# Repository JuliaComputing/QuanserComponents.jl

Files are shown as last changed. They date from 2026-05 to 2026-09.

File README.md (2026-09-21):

# QuanserComponents

Dyad models of the Quanser QUBE-Servo 3 with the rotary pendulum attachment (a Furuta
pendulum): a multibody plant, a clocked swing-up and balancing controller, and the
components that let the same controller run on the real device as a synchronous program.

https://github.com/user-attachments/assets/5ebe76e0-c05f-45de-a816-7d8e877a1d93

## Installation

The package and its Dyad dependencies are registered in the
[DyadRegistry](https://github.com/JuliaComputing/DyadRegistry); everything else comes from
the General registry. The generated Julia code is checked in, so the Dyad compiler is not
needed to use the package.

```julia
pkg> registry add https://github.com/JuliaComputing/DyadRegistry
pkg> add https://github.com/JuliaComputing/QuanserComponents.jl
```

or, for development, clone the repository and `pkg> dev path/to/QuanserComponents`.

The snippets below reach for four of the dependencies by name, so add them to the
environment as well:

```julia
pkg> add ModelingToolkit MultibodyComponents SynchToolkit OrdinaryDiffEqDefault
```

### The simulation-only branch

Those commands resolve `main` only for someone who can reach the repositories the MPC
controller is pinned to: MPCComponents is not registered, and `[sources]` names branch
a branch build of LinearMPC, two unregistered acados JLLs and one local checkout
(see [Environment](#environment) below). Everyone
else installs the branch `simulation-only`, which is `main` as of the commit before the
MPC work and resolves entirely to registered versions:

```julia
pkg> registry add https://github.com/JuliaComputing/DyadRegistry
pkg> add https://github.com/JuliaComputing/QuanserComponents.jl#simulation-only
```

`Manifest.toml` and `test/Manifest.toml` are checked in there and contain no repository
revisions, so a clone plus `Pkg.instantiate()` reproduces the versions the branch was
verified against. It carries the multibody plant, the energy swing-up and balancing
controller, the hardware programs and the C export -- everything but `FurutaMPC` and its
closed loops -- and its test suite passes with no device attached.

## Simulating the swing-up

`FurutaSwingup` is the closed loop: the multibody `QubePendulum` plant, the discrete-time
`SwingupWithHoming` controller on a 5 ms clock, samplers and a zero-order hold. The controller
is a clocked partition of the model; `SynchToolkit.compile_lustre` compiles it beside the
continuous plant so the ODE solver can step the two together.

```julia
using QuanserComponents
using ModelingToolkit, MultibodyComponents, SynchToolkit
using OrdinaryDiffEqDefault

@named model = FurutaSwingup()
ssys = multibody(model, additional_passes = [SynchToolkit.compile_lustre])
prob = ODEProblem(ssys, [
    ssys.qubependulum.shoulder_joint.render => false
    ssys.qubependulum.elbow_joint.phi => deg2rad(0.15)   # start almost exactly hanging down
    ssys.qubependulum.shoulder_joint.phi => 0.0
    ssys.gain.k => 1.0                                   # actuator gain seen by the plant
], (0.0, 10.0))
sol = solve(prob; dt = 0.005)

phi = sol[ssys.qubependulum.elbow_joint.phi]
rad2deg(abs(mod2pi(phi[end]) - pi))   # deviation from upright at t = 10 s, about 0.004 degrees
```

The plant uses the `identified` parameter set while the controller was tuned for the
datasheet values, so the first swing-up attempt is not caught: the arm runs out of bounds, the
controller re-homes and the second attempt holds. Useful signals to plot (with Plots.jl or
Makie in your own environment):

```julia
using Plots
plot(sol, idxs = [ssys.qubependulum.elbow_joint.phi,
                  ssys.qubependulum.shoulder_joint.phi,
                  ssys.zeroorderhold.y])                         # angles [rad] and motor voltage [V]
plot(sol, idxs = ssys.control_system.runtime.swingup_catch.neartop.y)   # stabilizer active
```

### 3D rendering

Rendering needs GLMakie in the environment (it is not a dependency of the package):

```julia
import GLMakie
using MultibodyComponents: render
render(model, sol, 0.0)                          # still at t = 0, with a time slider
render(model, sol; filename = "swingup.mp4")     # animation, real time at 30 frames per second
```

## Running on the hardware

`FurutaHardware` is the same controller with the plant replaced by `HardwareMeasurement`,
`HardwareCommand`, `HardwareDiagnostics` and a `DataLogger`. Because it is purely discrete,
`SynchToolkit.stkcompile` turns it into a standalone synchronous program. Every program in this
package is handled the same way: `compile_program(Model; ...)` compiles it, with everything the
program needs beyond its constructor declared once in the model's `ProgramSpec`, and the result
is put on the rig by one of three functions, each named for how it runs the program:

```julia
gen  = compile_program(FurutaHardware; Ts = 0.005)
ctrl = ProgramRuntime(gen; backend = :c, umax = 5.0)   # :julia or :c; the tunables by name
run_inprocess!(ctrl; Tf = 10)                          # a Julia timing loop ticks the node here
run_c!(gen; Tf = 10, deploy_host = "pi@192.168.1.49")  # standalone C, built and run here or on the Pi
run_ode!(FurutaMPCHardware, prob)                      # an ODE solver steps the model, paced by itself
```

`prob` is an `ODEProblem` over the model built with the spec's `ode_kwargs` (see `run_ode!`).

The `FurutaSwingupExperiment` analysis builds the program, exports the C, copies it to a Raspberry
Pi with the QUBE attached, builds and runs it there and streams the log back (`run_on_target`
picks between the in-process and the C route from the analysis' parameters). Without a device,
`FurutaSwingupExperiment(; run = false)` still builds and exports.

The hardware I/O calls into `csrc/qube_hw.c`, which needs the Quanser HIL SDK; the exported C
is built on the target for the same reason. See `test/runtests.jl` for how the controller is
built, stepped and compared across backends without a device attached.

## Nonlinear MPC swing-up (experimental)

`FurutaMPC` (dyad/furuta_mpc.dyad) replaces the whole swing-up state machine by one nonlinear
model-predictive controller, `MPCComponents.ACADOSMPC`: it swings the pendulum up and balances
it, with one real-time iteration per 10 ms tick over a horizon of 60 samples, the motor voltage
bounded to ±10 V and the arm angle and the velocities bounded softly. The prediction model is the
multibody `QubePendulum` itself: `FurutaPredictionModel` (dyad/furuta_mpc.dyad) is that plant plus
the one signal the swing-up term needs, and `furuta_mpc_dynamics()` (src/mpc.jl) does nothing but
compile it with `multibody` and hand it to `continuous_dynamics` with the `ForwardDiff` Jacobian
backend, which differentiates a numeric evaluation of the model. That backend exists because a multibody model's compiled form
contains cached linear solves that the default symbolic Jacobian cannot reconstruct; the same
fact rules out C export, so this controller runs on SynchJulia's Julia backend only.

The weighting is `design_lqr`'s (`Q1 = diag(1000, 10, 1, 1)`, `Q2 = 100`, terminal cost the LQR
cost-to-go about upright) plus one term that makes it swing up: *energy shaping in the stage
cost*. The prediction model carries the signal `pendulum_energy_ratio` (kinetic energy of the
rotation about the elbow plus the height of the centre of mass, normalized so that rest upright
is 1 and hanging at rest is 0, the quantity the energy swing-up controller pumps -- though not
by the same expression: `Energy` omits the parallel-axis term), and the MPC
weights it as a fifth controlled output with the reference 1 and the weight `energy_weight`
(1e5). The cost is then a nonlinear least squares, which `ACADOSMPC` gained for this (nonlinear
`outputs`, JuliaComputing/MPCComponents.jl#16). From rest the term gives the solver a gradient
towards pumping from the first tick; a soft *terminal set* on the energy, the previous design,
could not while the set was out of reach, and swung up in one to five seconds with a hesitant
first swing. Near upright the term vanishes quartically in the deviation (the energy error is
quadratic in the angle and in the velocity), and the closed loop from kicks up to 0.3 rad or
4 rad/s is identical to the LQR's, to the voltage. What the term does not change is the arm: under
LQR weights the swing-up still throws it past the end stops in 60 % of the rest starts (2.4 rad
median, up to 8.6 rad, see below), the same distribution as with the terminal set. The LQR arm
weight forbids the gentler pumping, a hard arm bound removes the swing-up altogether (the
real-time iteration fails), and a terminal set on the arm angle does not help either.
Three further details were found necessary by simulating the loop with quantized angles and the
discrete velocity estimators, and are documented on the components: the pendulum angle fed to the
LQR part is wrapped to [0, 2π) about the reference π (the 2π jump at the bottom costs a failed
solve that `reset_on_failure` recovers), soft velocity bounds and `ACADOSMPC`'s `reset_on_failure`
keep a shifted real-time iteration from derailing, and the velocity estimate must be nearly
unfiltered (`velocity_filter = 0.8`; the old default of 0.5 makes even the balancing unstable at
10 ms). HPIPM condenses the QP to 5 stages, which is the measured optimum of that setting
(`qp_cond_N`, swept in NOTES.md).

`FurutaMPCSwingup` is the closed loop around the simulated plant and `FurutaMPCHardware` the
hardware program, the counterparts of `FurutaSwingup` and `FurutaHardware`:

```julia
using QuanserComponents, ModelingToolkit, MultibodyComponents, SynchToolkit, OrdinaryDiffEqDefault
@named model = FurutaMPCSwingup()
ssys = multibody(model, additional_passes = [SynchToolkit.compile_lustre])
prob = ODEProblem(ssys, Pair[ssys.qubependulum.shoulder_joint.render => false,
                             ssys.qubependulum.elbow_joint.phi => deg2rad(0.15),
                             ssys.qubependulum.shoulder_joint.phi => 0.0], (0.0, 10.0))
sol = solve(prob; dt = 0.01)

ctrl = ProgramRuntime(compile_program(FurutaMPCHardware; Ts = 0.01, Np = 60))   # the hardware program, see test/hardware_mpc.jl
```

`test/hardware_mpc.jl` runs it on the rig. Two parameters are runtime-settable (`TuningGains`):
`command_umax`, a clamp on the command before the amplifier for a first run at reduced voltage,
and `velocity_filter`. The script then runs the same model against the device a second way, as a
simulation (`run_ode!`: `HardwareDiagnostics(realtime = true)` paces the ODE
solver's ticks on the wall clock, `output_trajectories = true` makes the MPC record its
predictions) and opens `MPCComponents.mpc_gui` on the solution to inspect the predicted
trajectories and the solver residuals tick by tick.

`test/mpc_rollouts.jl` ticks the compiled hardware program -- the very node the rig runs --
against a simulated pendulum (the multibody model with encoder quantization, RK4 at five
sub-steps per period, optionally with perturbed parameters) from random initial conditions (arm
within ±1.5 rad, pendulum anywhere, arm velocity within ±3 rad/s, pendulum velocity within
±10 rad/s) or from rest near hanging as the rig starts, and counts the rollouts in which the
pendulum stays within 0.1 rad of upright for the last second of 10 s. The summaries of four such
single-rate runs are in assets/mpc/ (the compiled program at the defaults above; the two multirate
summaries beside them belong to the section below):

| rollouts | plant | starts | balanced within 10 s | catch time median / 90 % | arm past the stops |
|---|---|---|---|---|---|
| 1000 | identified | random | 1000 | 0.94 s / 1.92 s | 714 (median 2.68 rad, max 12.3) |
| 200 | motor −15 %, arm +20 %, Jp +15 %, damping ×2 | random | 199 | 1.36 s / 3.89 s | 159 (median 3.21 rad, max 12.8) |
| 200 | identified | at rest near hanging, as on the rig | 200 | 1.08 s / 1.82 s | 120 (median 2.38 rad, max 8.58) |
| 200 | randomly perturbed per rollout (±15 % kt, ±20 % arm mass, ±15 % Jp, damping ½ to 2) | at rest near hanging | 200 | 1.08 s / 2.42 s | 128 (median 2.35 rad, max 8.95) |

Solve time was 0.98 to 1.26 ms per tick at the median and 2.2 to 2.6 ms at the 99th percentile;
about one solve in a thousand failed and was retried. Every rest start swings up within 2.5 s
at the 90th percentile and 5.7 s at worst; the one rollout not balanced at 10 s (perturbed plant,
random start) was still swinging. The arm column is the caveat of this design: in 60 % of the
rest starts and 70 % of the random ones the swing-up carries the arm past the ±1.92 rad end stops,
the same distribution the terminal-set design had (its summaries: 195 to 197 of 200 rest starts
balanced, catch median 2.2 s, 90 % 5 s, arm median 2.2 rad).

`qp_cond_N = 5` and the `ForwardDiff` Jacobian backend are both measured optima; the sweep behind
them, and why the sparse AD backends are of no use to this model, are in NOTES.md.

### Multirate: 1 kHz estimation, 200 Hz control

`FurutaMPCMultirate` splits the controller across two clocks -- the encoders read and the state
estimated at `Ts_fast` (1 ms), the MPC solved at `Ts` (5 ms) -- with `FurutaMPCMultirateSwingup`
and `FurutaMPCMultirateHardware` as the simulated and hardware loops. The single-rate models are
unchanged.

Sampling faster is not what makes it better. `VelocityEstimator` is a backward difference through
an exponential filter, which assumes the velocity is locally constant; a swinging pendulum's is
not, so its estimate carries an acceleration-induced bias that no filter tuning removes, and
running it at 1 ms instead of 10 ms measures *worse* while balancing. Estimating the acceleration
as well removes the bias: the two `DiscreteComponents.AlphaBetaGammaFilter`s score 0.035 rad/s RMS
balancing and 0.243 during the swing-up, against 0.141 and 1.280 for the 10 ms baseline. And a
window long enough to do that is only affordable at 1 ms. The measurements, the two metrics that
turned out to be misleading, and the cost of a third-order tracker on a fast disturbance are in
NOTES.md.

The clock transition is `DiscreteComponents.Latest`. It does not *relate* the two clocks: both are
declared separately, and only convention makes one five times the other. A block cannot derive one
clock from another, so an integer rate relationship that is stated once and checked belongs at the
compiler level instead.

```julia
@named model = FurutaMPCMultirateSwingup(; Ts = 0.005, Ts_fast = 0.001)
ssys = multibody(model, additional_passes = [SynchToolkit.compile_lustre])
sol = solve(ODEProblem(ssys, Pair[ssys.qubependulum.elbow_joint.phi => deg2rad(0.15)],
                       (0.0, 4.0)); dt = 0.001)          # step the *fastest* clock

ctrl = ProgramRuntime(compile_program(FurutaMPCMultirateHardware; Ts = 0.005, Ts_fast = 0.001,
                                      Np = 60, horizon = 0.6))
out = ctrl()        # one 1 ms tick; the MPC fires on every 5th, `nothing` in between
```

The 5 ms period does not cost horizon, because the shooting grid is not uniform: `horizon` is the
span the `Np` intervals cover, and `MPCComponents.linear_time_steps` grows them from `Ts` to cover
it, so the 0.6 s the 8 ms controller had costs 60 decision variables instead of the 120 a uniform
5 ms grid would need. The first interval stays at `Ts`, the one whose control is applied, and the
last is 15 ms, which is as far as the grid is stretched: the integrator takes one step per
interval, and beyond that the far end of the horizon stops predicting anything.
`horizon = Np * Ts` gives the uniform grid back, and NOTES.md records the effect of each -- the
rate, not the horizon, is where the improvement comes from.

`test/mpc_rollouts.jl` ticks this program too, as `rate = multi`, and the two multirate summaries
in assets/mpc/ are the counterparts of the single-rate table above: 50 of 50 balanced from both
start sets, the catch at 0.35 s from rest and 0.99 s from the random operating space against the
single-rate 1.08 s and 0.94 s, and the solve at 0.98 ms of the 5 ms period at the median and 1.8 to
2.2 ms at the 99th percentile.

`compile_program` reads the two clocks off the model, the compiled node takes one boolean per clock
and `ProgramRuntime` generates that pattern, so the driver still ticks once per `Ts_fast`; there is
no C harness for it, since `run_hardware.c` drives a single tick.

### Environment

MPCComponents is not registered, and the MPC stack it needs is not all released. What is still
pinned is an unregistered LinearMPC fork and the two acados JLLs.

DiscreteComponents comes from DyadRegistry as of 0.4.0, which carries both `AlphaBetaGammaFilter`,
the velocity estimator of the multirate model (JuliaComputing/DiscreteComponents.jl#119), and
`Latest`, its clock transition (JuliaComputing/DiscreteComponents.jl#121). The bound is `0.4`
rather than `0.3` because that release removed `LastValue`, which `Latest` replaces.

The whole Synch stack comes from DyadRegistry too. SynchJulia is 0.8.1, and SynchCompiler no longer
exists, having been merged into SynchJulia by JuliaComputing/SynchJulia.jl#205. SynchToolkit is
0.5.1 (JuliaComputing/SynchToolkit.jl#214), which has both the `Latest` clock-crossing operator
the multirate model needs (JuliaComputing/SynchToolkit.jl#199) and, through the clock rework of
JuliaComputing/SynchToolkit.jl#186, the array clocked variables the MPC's outputs are. Registry
0.5.0 has neither, so `[compat]` reads `SynchToolkit = "0.5.1"`; with 0.5.0, compiling
`FurutaMPCHardware` fails inside `stkcompile` with

```
KeyError: key (control_system₊mpc₊u(t))[1] not found
```

This branch checks in `Manifest.toml` and `test/Manifest.toml`, resolved against the pinned stack.
MPCComponents comes from its GitHub `main` (which has to include
[JuliaComputing/MPCComponents.jl#31](https://github.com/JuliaComputing/MPCComponents.jl/pull/31):
without it the multibody prediction model is rejected as time-varying), and one package has to
come from a local checkout recorded relative to this repository: `../MultibodyComponents` (the
`~/.julia/dev` checkout; the registered release does not resolve against these pins). With both
next to the repo,

```
julia --project=path/to/QuanserComponents -e 'using Pkg; Pkg.instantiate()'   # the package
julia --project=path/to/QuanserComponents/test test/hardware_mpc.jl           # the scripts
```

is all it takes. For an environment of your own, copy the `[sources]` block (and the `[extras]`
entries they refer to) from Project.toml into it. The first `using` precompiles the multibody and
acados trees, a few minutes.

## Layout

```
dyad/        the Dyad models: plant, controllers (swing-up state machine and MPC), hardware I/O, analyses
generated/   Julia code generated from dyad/ (checked in)
src/         hand-written Julia: hardware operators, program compilation, C export, deployment
csrc/        the C side: Quanser HIL I/O, logging, trajectory replay, the run_hardware harness
assets/      component icons, QUBE meshes and textures
examples/    parameter identification scripts (their own environment, see examples/Project.toml)
test/        test suite (its own environment, see test/Project.toml), the hardware run scripts and the MPC Monte Carlo
```

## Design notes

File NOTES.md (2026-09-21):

# Development notes

## FurutaMPC: the solver settings, and where the tick goes

Measured by ticking the compiled program (a `ProgramRuntime`, the very node the rig runs) against the
simulated plant -- `test/mpc_rollouts.jl`'s harness with the timing kept and the plots dropped --
24 rollouts of 6 s per configuration from the same initial conditions (3 from rest near hanging,
21 from the random operating space), 14 400 ticks each, every configuration swinging up and
balancing in all 24. Timings are the wall time of one `ctrl()` call, which is the hardware read,
the velocity estimators, the acados solve, the write and the log row.

`qp_cond_N`, the horizon HPIPM partially condenses the QP to, is the one setting of the two with a
real effect, and the existing default of 5 is its optimum:

| `qp_cond_N` | 1 | 2 | 3 | **5** | 10 | 20 | 30 | -1 (= 60) |
| --- | ---- | ---- | ---- | --- | ---- | ---- | ---- | --- |
| median tick [ms] | 1.45 | 1.01 | 0.98 | **0.97** | 1.00 | 1.07 | 1.13 | 1.30 |
| 99th %ile tick [ms] |  5.9 |  4.3 |  3.1 |  **2.3** |  2.5 |  3.0 |  3.5 | 5.1 |

3 to 10 are within a few percent of each other, so the setting is not delicate; condensing to 1 or
2 stages costs more than it saves, and the uncondensed horizon costs 34 % at the median and 2.2× at
the 99th percentile. The profile has the same shape and the same optimum under the `FiniteDiff`
backend (0.93 / 0.93 / 0.96 / 1.03 / 1.26 ms at the median for 3, 5, 10, 20, -1), so the optimum is
a property of the QP and not of how the model is differentiated -- which is the answer to whether a
different Jacobian backend would move it.

Of the ~0.97 ms tick, about half is the prediction model. The Jacobian costs 3.3 µs (minimum) to
4.5 µs (median) per call and the right-hand side 0.6 µs, and ERK with 2 stages over 60 shooting
intervals evaluates them 120 times a tick. The rest is HPIPM and acados' own bookkeeping.

The tick also allocates 1.0 MB, which is neither acados' nor MPCComponents' doing: the numeric
right-hand side allocates 2.6 kB *per call* on its own (`@allocated dyn.f!`, steady state, not a
first-call effect) and the AD Jacobian 6 to 7 kB, inside the cached linear solve MTK compiles the
multibody model into (`ModelingToolkitTearing.safe_ldiv` builds and solves a fresh `LinearProblem`
each call). At 120 evaluations a tick that is the whole megabyte. It costs 9 % of tick time in
garbage collection and, worse, the occasional 40 to 150 ms tick -- 46 of 14 400 ticks over the 10 ms
period. That allocation, not the QP, is what a further round of tuning should attack; the horizon
and the condensing are already at their optimum.

## FurutaMPC: why the sparse AD Jacobian backends are of no use here

`ACADOSMPC` gained `SparseForwardDiff`/`SparseFiniteDiff` in
JuliaComputing/MPCComponents.jl#19 -- detect the Jacobian sparsity pattern once with
SparseConnectivityTracer, colour the columns, and evaluate one AD direction per colour instead of
one per entry of `[x; u]`. Updating to that pull request left every tick statistic of this
controller unchanged: 0.97 ms median, 2.3 ms at the 99th percentile and 993 kB per tick before and
after, and the same at `qp_cond_N` 10 and -1. Its other two improvements do not reach this model
either -- the allocation fix is for a `reshape` that ForwardDiff only performs above 12 AD
directions (this model has 5), and `cse` shares subexpressions in `build_function`-built code,
which here is only the tiny `pendulum_energy_ratio` output.

Two independent reasons the sparse backends cannot help:

1. **The pattern cannot be detected.** `continuous_dynamics(...; jacobian_backend =
   :sparse_forwarddiff)` throws at construction. Detection traces the right-hand side with
   SparseConnectivityTracer's *global* `GradientTracer`, which carries index sets and no value, so
   every comparison on it (`<`, `>`, `isless`, `<=`, `==` -- all registered as zero-derivative
   2-to-1 operators) returns another tracer rather than a `Bool`. The compiled multibody model
   reaches a linear solve, and its pivot search branches on a comparison:

       LinearAlgebra.generic_lufact!    stdlib/LinearAlgebra/src/lu.jl:170   `if absi > amax`
       LinearSolve.solve!               factorization.jl:697
       ModelingToolkitTearing.safe_ldiv reassemble.jl:715
       <the MTK generated control function>
       MPCComponents._acados_dynamics_numeric's f!

   giving `TypeError: non-boolean (GradientTracer{Int64, BitSet}) used in boolean context`.
   MPCComponents catches this and says to use the dense backend.

   SparseConnectivityTracer's own answer to a value-dependent branch is the *local* detector,
   `TracerLocalSparsityDetector`, whose `Dual` tracers do carry a primal, so the comparison returns
   a real `Bool` and the branch is taken as it would be at that point. That does trace this model,
   and the resulting sparse Jacobian equals the dense one exactly.

2. **The pattern has nothing to exploit.** With the local detector the pattern is 12 of 20 entries:

       ⋅  ⋅  1  ⋅  ⋅          (d/dt shoulder angle  = shoulder velocity)
       ⋅  ⋅  ⋅  1  ⋅          (d/dt elbow angle     = elbow velocity)
       1  1  1  1  1          (the two accelerations depend on everything,
       1  1  1  1  1           as a two-link manipulator's must)

   Rows 3 and 4 are dense, so no two of the five columns may share a colour: a column colouring
   needs 5 directions, exactly what dense forward AD already does. Measured, the sparse path through
   the local detector is 21 % *slower* per call (4.07 µs minimum against 3.35 µs) for the
   compression and decompression it adds. This is a property of the model, not of its size --
   any serial-link manipulator whose state is `[q; q̇]` has a Jacobian of this shape, and the
   acceleration block is dense in `q` and `q̇` whatever the link count. Sparse AD pays on models
   with weak coupling (a mass chain, a discretized PDE), not on this one.

So the dense `:forwarddiff` backend stays, and `furuta_mpc_dynamics` accepts the `:sparse_` names
only so that the comparison is one keyword away should detection ever work. `:finitediff` is a
shade faster at the median (0.93 ms) but worse where it matters -- 3.0 ms at the 99th percentile,
1.7 MB per tick against 1.0 MB, 114 of 14 400 ticks over the 10 ms period against 46 -- and its
Jacobian is only an approximation.

## The multirate MPC: what the fast clock actually buys

`FurutaMPCMultirate` samples the encoders and estimates the state at 1 ms while the MPC solves at
5 ms (8 ms when the measurements below were taken; the ratio is what they are about). The obvious
reading -- that sampling faster gives a better velocity estimate -- is wrong, and measuring it was
what led to the design.

The metric below is the RMS error of the velocity estimate against the truth, on an angle quantized
to real encoder counts, over trajectories the controller actually sees. It folds lag and noise into
the one number the LQR pays for. Two earlier metrics were discarded first, and both are worth
naming because they are the obvious ones to reach for:

  - **An impulse-response noise gain** assumes the encoder error is white. It is not: the QUBE's
    encoder is 2048 counts per revolution, so one count is 3.07 mrad and, at 1 ms, 3.07 rad/s.
    Below that speed the angle simply does not change between samples, and the error is a
    staircase strongly correlated with the trajectory.
  - **A phase-deficit lag** flatters any estimator whose internal model contains the test signal: a
    constant-jerk tracker scores exactly zero lag on a constant-acceleration ramp.

The balancing trajectory is a 0.3 rad oscillation at the pendulum's natural frequency (8.07 rad/s,
peak 2.4 rad/s -- under one count per tick, so quantization dominates); the swing-up is a 3.7 rad
one (peak 30 rad/s, ten counts per tick, so lag dominates).

| estimator | balance | swing | kick | impact |
| --- | --- | --- | --- | --- |
| difference + lowpass, 10 ms, `a = 0.8` (the single-rate controller) | 0.141 | 1.280 | 0.241 | 0.158 |
| difference + lowpass, 1 ms, `a = 0.1487` (equal time constant) | 0.164 | 1.067 | 0.164 | 0.147 |
| difference + lowpass, 1 ms, `a = 0.125` (equal lag) | 0.156 | 1.279 | 0.179 | 0.133 |
| linear-fit FIR differentiator, 16 taps at 1 ms | 0.110 | 1.275 | 0.202 | 0.103 |
| quadratic-fit FIR differentiator, 32 taps at 1 ms | 0.055 | 0.144 | 0.210 | 0.114 |
| alpha-beta tracker, 1 ms, `q = 1e4` | 0.104 | 0.642 | 0.141 | 0.102 |
| **alpha-beta-gamma tracker, 1 ms (`AlphaBetaGammaFilter`)** | **0.035** | **0.243** | 0.300 | 0.124 |

Three things fall out of it:

1. **Sampling the same estimator faster buys nothing.** Retuning the exponential filter to hold
   its time constant scores 0.164 against the baseline's 0.141 while balancing -- slightly worse --
   and only 16 % better on the swing-up. The estimator structure, not the rate, is the binding
   constraint. (An earlier version of this note claimed a `sqrt(10)` noise penalty for that
   retuning; that was wrong, because it compared at equal filter time constant and ignored that the
   difference's own half-sample lag drops from 5 ms to 0.5 ms. The real figure is about 1.16x.)
2. **Estimator *order* is what matters.** Every constant-velocity estimator is stuck near the
   baseline on the swing-up -- the 16-tap linear fit scores 1.275 against 1.280 -- because a
   swinging pendulum's velocity is never locally constant, so the estimate carries an
   acceleration-induced bias that no bandwidth choice removes. Fitting the acceleration removes it.
3. **The fast clock is what makes order 2 affordable.** A 32 ms window costs 32 samples at 1 ms and
   3 at 10 ms, and 3 samples cannot support a quadratic fit's noise rejection. So the two halves of
   the design are one decision, not two.

`AlphaBetaGammaFilter` was upstreamed to DiscreteComponents (#119) rather than written here. Its
`beta` default is the same Kalata steady-state relation the alpha-beta filter already used --
solving the Riccati recursion for the constant-acceleration model reproduces it to 0.002 % -- and
`gamma = beta^2/(2*alpha)` completes it to within 0.2 %.

The cost is in the last two columns. On a 60 rad/s disturbance, far above the pendulum's own
8.07 rad/s and above anything the motor can excite, the third-order tracker is worse than the
baseline (0.300 against 0.241): a model that extrapolates acceleration overshoots on something that
is not accelerating smoothly. The constant-acceleration model also only pays when the signal is
oversampled -- on a sine the crossover is near `w*Ts = 0.15`, and at 1 ms with the pendulum's
`w = 8.07` we sit at 0.008, three orders inside the useful regime. `velocity_alpha` stays runtime-
settable, and `test/mpc_rollouts.jl` is where it should be swept, since it is the only place
encoder quantization is simulated in closed loop.

## Two clocks through `stkcompile`

Three findings from making the multirate program, none of them documented upstream:

  - **`stkcompile` takes more than one `InputClock`.** Each becomes one `Bool` argument of the
    generated node, in the order the `inputs` vector lists them, so a two-clock program is stepped
    as `step!(exe, tick_fast, tick_slow, gains, auto)`.
  - **An output on a clock that did not tick comes back as `nothing`**, so slow-clock outputs are
    `Union{Nothing, Float64}`. That is why `MPC_OUTPUT_NAMES`' `u` and `exitflag` are empty on
    four ticks out of five.
  - **`InputClock(clk; name = ...)` does not work** on this SynchToolkit: `build_input` calls
    `insert_clock(::LustreTranslator, ...)`, which has only a `Dict` method. The clocks are left
    unnamed. Fixed upstream by SynchToolkit.jl#189, which is on `main` but not on the branch this
    package pins.

The MPC's clock cannot be *derived* inside the node instead: `VariableClock`/`ClockValue` codegen
dereferences a `_runtime` that only `compile_sim` installs, so those clocks are simulation-only,
and any clock that is not declared as an `InputClock` is emitted as an unbound identifier.

`ProgramRuntime` therefore generates the tick pattern itself from an integer divisor rather than
taking it from the caller. Raising the slow tick without the fast one compiles and runs, silently
on the previous period's measurements, so the phase is a property of the runtime and `reset!` puts
it back.

## The 1 ms slot does not hold the MPC solve

Per 5 ms period the work is five fast ticks -- an encoder read and two filter updates each, a
microsecond at the median -- plus one solve of about 0.98 ms. That is roughly 20 % utilization, so
the *loop* is comfortable. The *slot* is not: the tick that carries the solve costs 0.98 ms of a
1.0 ms slot before the encoder read is counted, and 1.8 ms at the 99th percentile eats the next
fast slot, which then fires back to back. One of every five encoder samples therefore arrives with
a `dt` of about 0 rather than 1 ms -- on the very clock whose purpose is a clean 1 kHz estimate.
The 100 to 750 ms tail ticks (0.3 % of solves, the allocation problem above) swallow 100 to 750
fast slots.

`run_inprocess!` keeps an absolute schedule and never skips, so this is jitter rather than failure,
and the `dt` and `exec` log columns measure it directly. If a rig run shows it mattering, `Ts_fast`
is structural: a 2.5 ms base with a divisor of 2 keeps the 5 ms MPC and puts the solve at a third
of a slot. Worth checking first is whether the device sustains 1 kHz reads at all -- each
`hil_read` is a transaction of order 100 to 300 us, and the `exec` column of an existing 5 ms
swing-up log gives the real number.

## The non-uniform shooting grid: the effect of the rate, and of the horizon

The MPC's period and its prediction horizon used to be one number: `Np` uniform intervals of
length `Ts`, so the 0.6 s horizon cost 75 decision variables at 8 ms and would have cost 120 at
5 ms. JuliaComputing/MPCComponents.jl#44 breaks that link. `ACADOSMPC`'s `time_steps` gives the
length of each shooting interval separately, and `linear_time_steps(Ts, Np, Tf)` grows them by a
constant increment from `Ts` to cover `Tf`; the first interval stays at `Ts`, since its control is
the one the component applies and holds for a clock period, and the stage cost of interval `k` is
weighted by `Δt_k / Ts` so that a long interval counts for as much as the short ones it replaces.
`FurutaMPCMultirate` therefore has a `horizon` parameter beside `Ts` and `Np`, and at its defaults
60 intervals grow from 5 ms to 15 ms and span 0.6 s.

Measured with `test/mpc_rollouts.jl` in its multirate mode -- the compiled program ticked against
the simulated pendulum with the QUBE's encoder quantization, 50 rollouts of 10 s from the same
seeds, the identified plant, `qp_cond_N = 5` -- every configuration below swung up and balanced in
all 50, from rest near hanging and from the random operating space alike:

| `Ts` / `Np` / horizon | grid | catch median / 90 % / max [s] | solve median / 99 % [ms] | status ≠ 0 |
| --- | --- | --- | --- | --- |
| 8 ms / 75 / 0.60 s (the previous default) | uniform | 1.04 / 1.64 / 2.19 | 1.23 / 2.78 | 0 of 62 500 |
| 5 ms / 60 / 0.60 s (the default now) | linear, 5 → 15 ms | 0.35 / 1.19 / 4.16 | 0.98 / 1.77 | 0 of 100 000 |
| 5 ms / 60 / 0.60 s, `integrator_stages = 4` | linear | 0.42 / 1.03 / 7.67 | 1.62 / 2.77 | 0 of 100 000 |
| 5 ms / 60 / 0.30 s | uniform | 0.34 / 0.55 / 1.10 | 0.98 / 1.23 | 0 of 100 000 |

and from the random operating space, where a long horizon should have the most to say:

| `Ts` / `Np` / horizon | catch median / 90 % / max [s] | arm median [rad] | solve median / 99 % [ms] | status ≠ 0 |
| --- | --- | --- | --- | --- |
| 8 ms / 75 / 0.60 s, uniform | 1.14 / 1.88 / 3.51 | 2.81 | 1.24 / 2.92 | 98 of 62 500 |
| 5 ms / 60 / 0.60 s, linear | 0.99 / 1.74 / 5.99 | 2.32 | 0.98 / 2.21 | 226 of 100 000 |
| 5 ms / 60 / 0.30 s, uniform | 0.80 / 1.26 / 1.56 | 2.33 | 0.98 / 1.94 | 176 of 100 000 |

Four things fall out of it:

1. **The rate accounts for the improvement.** Against the 8 ms controller the solve falls from 1.23 to 0.98 ms at
   the median and from 2.78 to 1.77 at the 99th percentile while the horizon stays 0.6 s, the
   swing-up from rest is caught in a third of the time, and the arm goes past the end stops in 7 of
   50 rest starts instead of 27. The period is 3 ms shorter, so utilization rises from 15 % to
   20 %; the loop is still far from full.
2. **The horizon does not.** A uniform grid at the same `Ts` and `Np` -- half the span, 0.3 s --
   catches sooner at every quantile that matters (0.80 against 0.99 s at the median from random
   starts, 1.26 against 1.74 at the 90th percentile, 1.56 against 5.99 in the worst rollout) and
   returns a nonzero acados status on 0.18 % of solves against 0.23 %, at the same solve time.
   `energy_weight = 1e5` on the pendulum's energy error makes the stage cost a shaping term that
   plans the pump without needing to see the catch, and stretching the grid both dilutes that
   near-term shaping with stage weights of up to 3 and pushes the terminal LQR cost -- the only
   term that knows about balancing -- twice as far out. `horizon = Np * Ts` is the whole change
   back. The horizon is kept at 0.6 s because that is what the 8 ms controller had and what the
   weights were tuned against, not because the measurements favour it.
3. **The grid is stretched only as far as the integrator can follow.** acados integrates every
   interval with one step of the same scheme, so the last interval is integrated three times more
   coarsely than the first. Against a finely integrated reference over the states a swing-up
   traverses, one step of the 2-stage scheme is off by at most

   | interval | 5 ms (the first) | 8 ms (the previous default, everywhere) | 15 ms (the last) | 27 ms |
   | --- | --- | --- | --- | --- |
   | 2-stage ERK | 0.034 | 0.128 | 0.600 | 4.08 |
   | 4-stage ERK | 0.0010 | 0.0044 | 0.0326 | 0.332 |

   in rad/s of state error. At 15 ms the worst interval of the horizon is a factor of five coarser
   than what the previous default accepted on every interval, which is the reason the horizon is
   0.6 s and not longer: at `horizon = 0.8` and `Np = 50` the last interval is 27 ms and its error
   is 4 rad/s, which is no longer a prediction of anything. Recovering the accuracy with
   `integrator_stages = 4` costs 66 % more solve time and does not swing up better (the median
   catch is worse and the worst rollout is worse), so the default stays 2.
4. **`qp_cond_N = 5` survives the change.** Re-swept on this grid (12 rollouts from rest, 24 000
   solves each), the median is 1.02 / 0.98 / 0.98 / 1.01 / 1.30 ms and the 99th percentile
   2.67 / 2.16 / 2.19 / 2.44 / 4.61 for 2 / 3 / 5 / 10 / -1 -- the same shape as at `Np = 60` on
   the single-rate controller: 3 to 10 within a few percent, 2 and the uncondensed horizon worse.

The grid reaches the whole controller, not only the solver: with `reference_preview` a preview
block would be tied to the shooting nodes rather than to multiples of `Ts` (this controller
previews nothing), and `penalize_increments` is refused outright on a non-uniform grid, which is
why `FurutaMPC`'s `penalize_increments = false` is load-bearing here.

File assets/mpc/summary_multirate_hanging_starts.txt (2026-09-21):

MPC Monte Carlo: 50 rollouts of 10 s, multirate, plant = identified, starts = hanging
MPC: Ts = 0.0050 s, sensing at 0.0010 s (divisor 5), everything else at the model's defaults
successes (upright within 0.10 rad for the last 1.0 s): 50 / 50 = 100.0%
catch time [s]: median 0.35, 90% 1.19, max 4.16
arm excursion max |phi| [rad]: median 1.54, max 4.13 (end stops at 1.92); rollouts beyond the stops: 7
|u| max over all rollouts: 10.00 V
acados exitflag != 0 on 0 of 100000 solves (status 2, iteration limit, on 0)
solve tick [ms]: median 0.978, 99% 1.770, max 746.880; 285 of 100000 beyond the 5.0 ms MPC period
fast tick [ms]: median 0.001, 99% 0.003, max 0.058; 0 of 400000 beyond the 1.0 ms sensing period
wall time 2.1 min (0.25 ms per tick incl. the plant simulation)

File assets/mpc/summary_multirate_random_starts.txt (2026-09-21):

MPC Monte Carlo: 50 rollouts of 10 s, multirate, plant = identified, starts = random
MPC: Ts = 0.0050 s, sensing at 0.0010 s (divisor 5), everything else at the model's defaults
successes (upright within 0.10 rad for the last 1.0 s): 50 / 50 = 100.0%
catch time [s]: median 0.99, 90% 1.74, max 5.99
arm excursion max |phi| [rad]: median 2.32, max 5.30 (end stops at 1.92); rollouts beyond the stops: 32
|u| max over all rollouts: 10.00 V
acados exitflag != 0 on 226 of 100000 solves (status 2, iteration limit, on 0)
solve tick [ms]: median 0.979, 99% 2.212, max 115.293; 290 of 100000 beyond the 5.0 ms MPC period
fast tick [ms]: median 0.001, 99% 0.003, max 0.055; 0 of 400000 beyond the 1.0 ms sensing period
wall time 2.1 min (0.25 ms per tick incl. the plant simulation)

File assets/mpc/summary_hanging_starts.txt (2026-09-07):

MPC Monte Carlo: 200 rollouts of 10 s, Ts = 0.010 s, Np = 60, plant = identified, starts = hanging
successes (upright within 0.10 rad for the last 1.0 s): 200 / 200 = 100.0%
catch time [s]: median 1.08, 90% 1.82, max 3.68
arm excursion max |phi| [rad]: median 2.38, max 8.58 (end stops at 1.92); rollouts beyond the stops: 120
|u| max over all rollouts: 10.00 V
acados exitflag != 0 on 34 of 200000 ticks (status 2, iteration limit, on 0)
tick execution time [ms]: median 0.992, 99% 2.225, max 634.096
wall time 4.0 min (1.21 ms per tick incl. the plant simulation)

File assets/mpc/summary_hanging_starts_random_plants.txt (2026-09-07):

MPC Monte Carlo: 200 rollouts of 10 s, Ts = 0.010 s, Np = 60, plant = random, starts = hanging
successes (upright within 0.10 rad for the last 1.0 s): 200 / 200 = 100.0%
catch time [s]: median 1.08, 90% 2.42, max 5.67
arm excursion max |phi| [rad]: median 2.35, max 8.95 (end stops at 1.92); rollouts beyond the stops: 128
|u| max over all rollouts: 10.00 V
acados exitflag != 0 on 41 of 200000 ticks (status 2, iteration limit, on 0)
tick execution time [ms]: median 1.264, 99% 2.506, max 631.448
wall time 4.8 min (1.44 ms per tick incl. the plant simulation)

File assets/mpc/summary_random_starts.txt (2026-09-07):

MPC Monte Carlo: 1000 rollouts of 10 s, Ts = 0.010 s, Np = 60, plant = identified, starts = random
successes (upright within 0.10 rad for the last 1.0 s): 1000 / 1000 = 100.0%
catch time [s]: median 0.94, 90% 1.92, max 4.22
arm excursion max |phi| [rad]: median 2.68, max 12.32 (end stops at 1.92); rollouts beyond the stops: 714
|u| max over all rollouts: 10.00 V
acados exitflag != 0 on 238 of 1000000 ticks (status 2, iteration limit, on 0)
tick execution time [ms]: median 0.978, 99% 2.186, max 1067.928
wall time 19.5 min (1.17 ms per tick incl. the plant simulation)

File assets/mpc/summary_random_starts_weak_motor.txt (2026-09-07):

MPC Monte Carlo: 200 rollouts of 10 s, Ts = 0.010 s, Np = 60, plant = perturbed, starts = random
successes (upright within 0.10 rad for the last 1.0 s): 199 / 200 = 99.5%
catch time [s]: median 1.36, 90% 3.89, max 8.16
arm excursion max |phi| [rad]: median 3.21, max 12.79 (end stops at 1.92); rollouts beyond the stops: 159
|u| max over all rollouts: 10.00 V
acados exitflag != 0 on 164 of 200000 ticks (status 2, iteration limit, on 0)
tick execution time [ms]: median 0.996, 99% 2.637, max 623.534
wall time 4.1 min (1.22 ms per tick incl. the plant simulation)

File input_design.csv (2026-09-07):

u
0.0000
0.0001
0.0003
0.0006
0.0010
0.0016
0.0022
0.0029
0.0037
0.0045
0.0054
0.0063
0.0071
0.0080
0.0087
0.0094
0.0100
0.0105
0.0108
0.0109
0.0107
0.0103
0.0096
0.0086
0.0072
0.0054
0.0032
0.0004
-0.0028
-0.0065
-0.0108
-0.0157
-0.0213
-0.0274
-0.0343
-0.0418
-0.0500
-0.0589
-0.0685
-0.0787
-0.0897
-0.1013
-0.1136
-0.1265
-0.1399
-0.1540
-0.1685
-0.1835
-0.1989
-0.2146
-0.2306
-0.2467
-0.2630
-0.2793
-0.2956
-0.3117
-0.3275
-0.3430
-0.3581
-0.3726
-0.3864
-0.3995
-0.4116
-0.4228
-0.4329
-0.4418
-0.4494
-0.4556
-0.4603
-0.4634
-0.4648
-0.4645
-0.4623
-0.4581
-0.4520
-0.4439
-0.4336
-0.4212
-0.4066
-0.3898
-0.3708
-0.3495
-0.3260
-0.3003
-0.2723
-0.2422
-0.2099
-0.1756
-0.1391
-0.1007
-0.0604
-0.0183
0.0256
0.0710
0.1180
0.1664
0.2161
0.2669
0.3188
0.3715
0.4248
0.4788
0.5331
0.5877
0.6423
0.6968
0.7511
0.8048
0.8580
0.9103
0.9617
1.0119
1.0608
1.1083
1.1541
1.1980
1.2401
1.2800
1.3177
1.3531
1.3859
1.4161
1.4437
1.4684
1.4902
1.5090
1.5248
1.5375
1.5470
1.5533
1.5565
1.5564
1.5532
1.5467
1.5370
1.5241
1.5082
1.4892
1.4672
1.4422
1.4144
1.3838
1.3506
1.3148
1.2765
1.2358
1.1929
1.1478
1.1007
1.0518
1.0011
0.9487
0.8948
0.8396
0.7831
0.7254
0.6667
0.6072
0.5468
0.4858
0.4242
0.3621
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

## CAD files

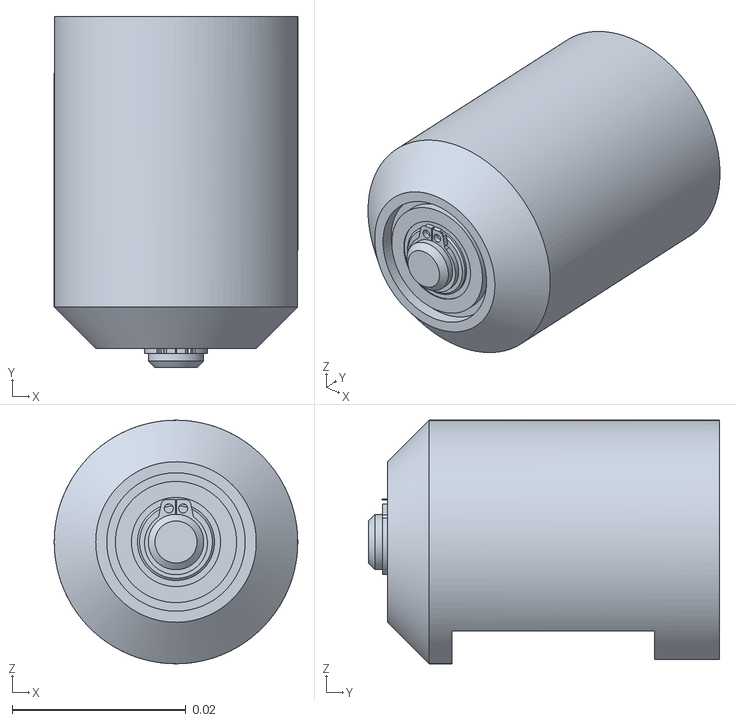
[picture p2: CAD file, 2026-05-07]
assets/qube/qube_motor_main.stl
0.028 x 0.0404 x 0.028

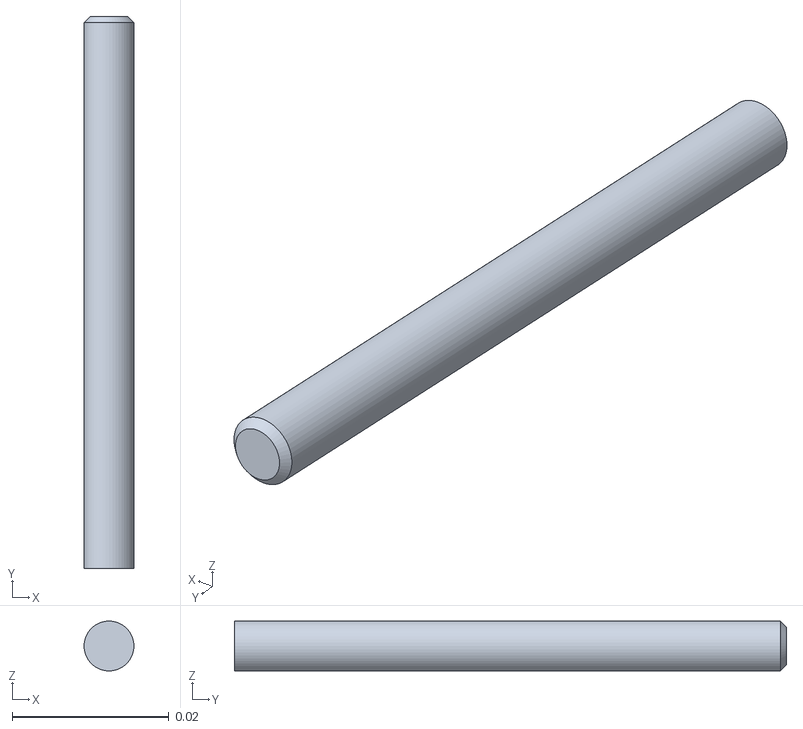
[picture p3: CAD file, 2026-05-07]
assets/qube/qube_arm.stl
0.00637 x 0.0705 x 0.00637

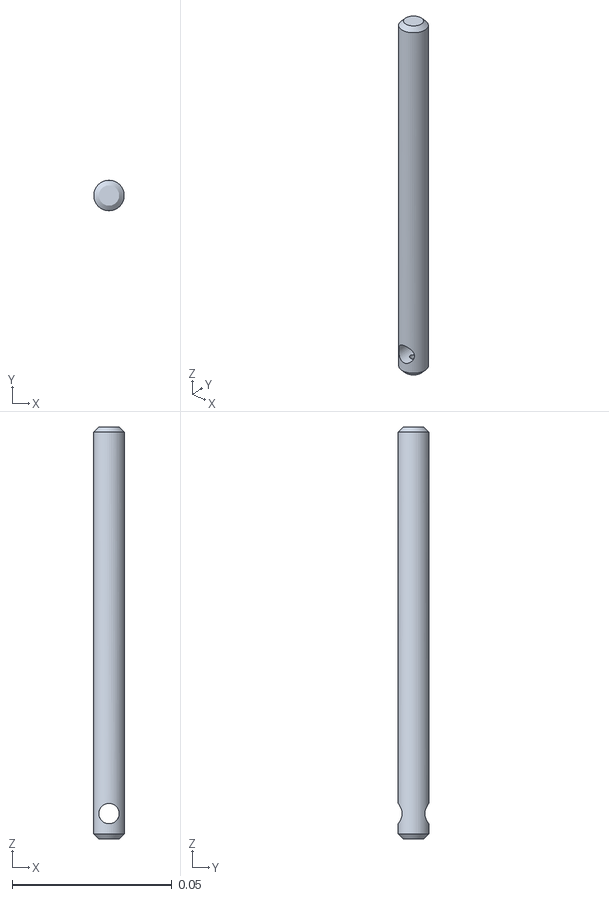
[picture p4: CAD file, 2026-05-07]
assets/qube/qube_pole.stl
0.00956 x 0.00956 x 0.129

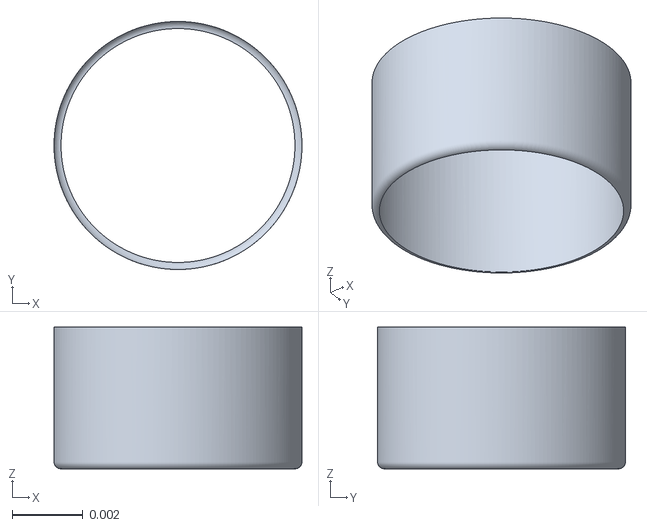
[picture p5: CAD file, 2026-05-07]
assets/qube/qube_motor_part.stl
0.00702 x 0.00702 x 0.00401

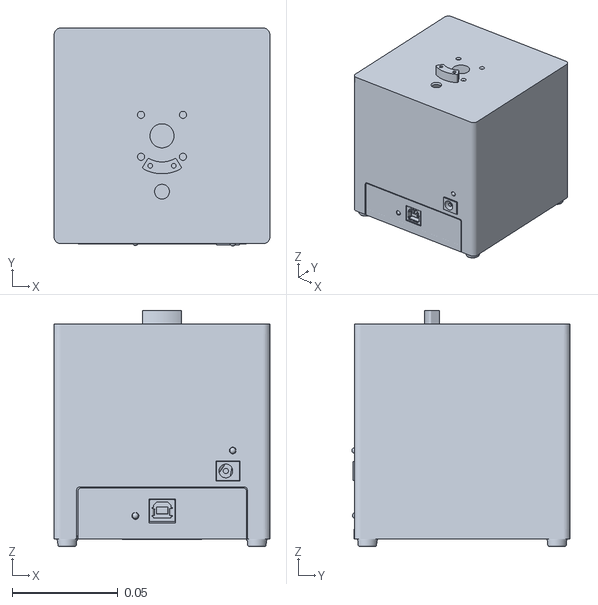
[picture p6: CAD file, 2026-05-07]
assets/qube/qube_block.stl
0.102 x 0.103 x 0.112

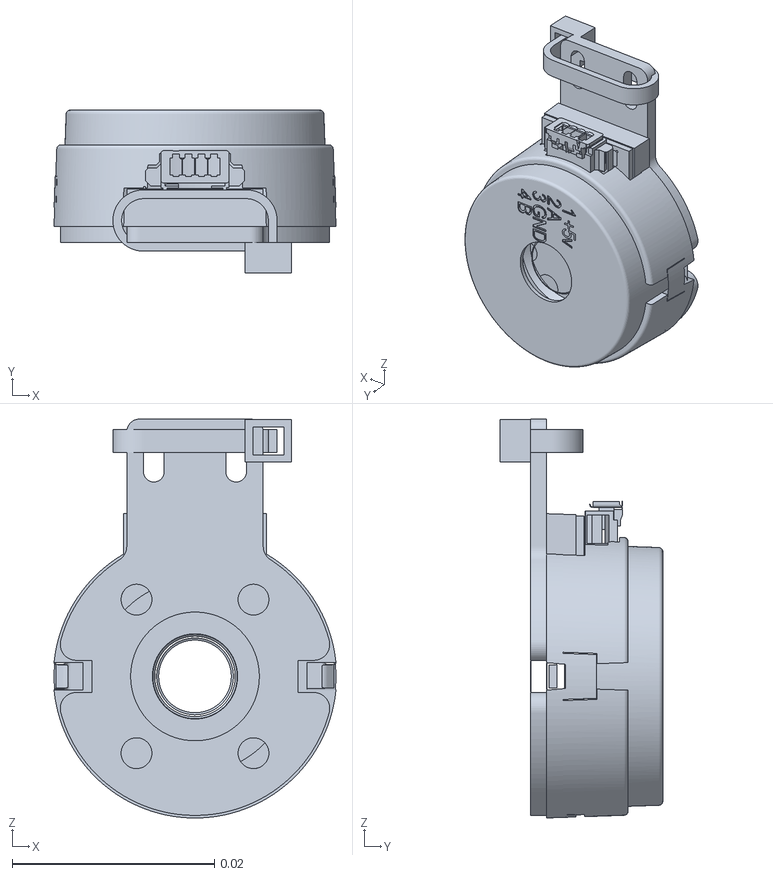
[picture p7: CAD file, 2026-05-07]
assets/qube/qube_motor_front.stl
0.0279 x 0.0161 x 0.0395

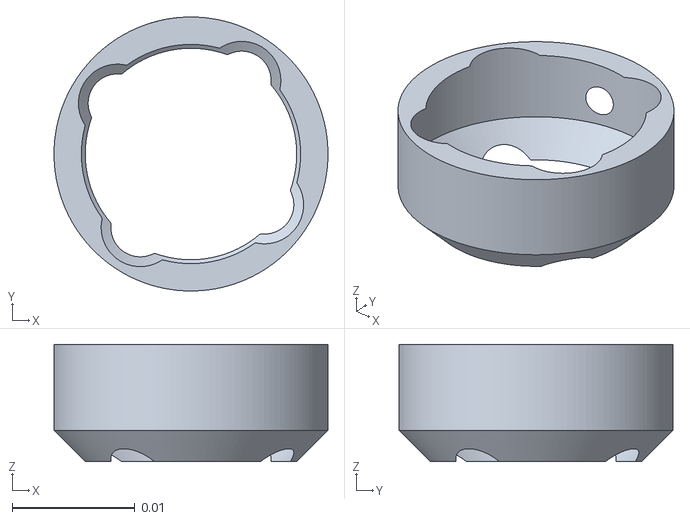
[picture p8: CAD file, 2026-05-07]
assets/qube/qube_motor_drive.stl
0.0223 x 0.0223 x 0.00956

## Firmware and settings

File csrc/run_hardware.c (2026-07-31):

/* Standalone control loop for an exported QUBE program.
 *
 * The program does its own encoder reads, motor writes and log rows (through qube_hw.c and
 * qube_log.c, the same implementations the Julia backend calls), so this is only timing:
 * open the device, open the log for the program to write into, tick the clock every Ts.
 *
 * Nothing here knows which program it is running. The node's outputs are never read — the
 * program logs what it wants logged, in the columns its own DataLogger was built with — so
 * the same loop serves the swing-up controller, the friction experiment, or anything else
 * built for this rig. What does depend on the program — the mangled node symbols, the
 * serialized parameter blocks, the sample time, the run duration and the log's identity —
 * arrives through run_hardware_config.h, which
 * `QuanserComponents.emit_hardware_harness` generates next to this file. That keeps this a
 * normal C file: editable, clang-format-able, and compilable in place rather than a Julia
 * string. Build with `make`. */
#define _GNU_SOURCE
#include <stdio.h>
#include <stdlib.h>
#include <string.h>
#include <time.h>
#include <signal.h>
#include <stdint.h>

#include "qube_hw.h"
#include "qube_log.h"
#include "qube_traj.h"
#include "top.h"
#include "run_hardware_config.h"

static volatile sig_atomic_t stop_flag = 0;
static void on_signal(int sig) { (void)sig; stop_flag = 1; }

/* elapsed seconds a - b for two CLOCK_MONOTONIC timestamps */
static double tsub(struct timespec a, struct timespec b) {
    return (double)(a.tv_sec - b.tv_sec) + (double)(a.tv_nsec - b.tv_nsec) * 1e-9;
}

int main(void) {
    signal(SIGINT, on_signal);
    signal(SIGTERM, on_signal);

    /* Opening in HIL mode enables the amplifier, zeroes the motor and records the
     * current encoder counts as homing offsets. Let the pendulum hang straight down
     * (0 = down, pi = up); the arm may be anywhere, as long as QUBE_ARM0 says where.
     * A swing-up program's GoHome then drives the arm to centre. */
#ifdef QUBE_CARD_OPTIONS
    qube_hw_set_card_options(QUBE_CARD_OPTIONS);   /* pin the command-to-torque path */
#endif
    if (qube_hw_open(QUBE_HW_MODE_HIL, QUBE_ARM0) != 0) return 1;
    fprintf(stderr, "run_hardware: card options = %s\n", qube_hw_card_options());

    /* The log the program writes its rows into. Opening it here rather than inside the
     * program is not a split of responsibility: a file name cannot cross a synchronous
     * node's interface (every signal there is a double), so the name travels as a
     * build-time constant and arrives in this header. qube_log.c line-buffers, which is
     * what makes a live plot of a run in progress smooth. */
    if (qube_log_open(QUBE_LOG_FILE, QUBE_LOG_HEADER, QUBE_LOG_NCOLS) != 0) {
        fprintf(stderr, "run_hardware: could not open %s for writing\n", QUBE_LOG_FILE);
        qube_hw_close();
        return 1;
    }

    /* An input sequence to replay, for the programs that have one. Same arrangement as the
     * log: the name cannot cross the node's interface, so it arrives as a build-time constant
     * in this header and the loop hands it to qube_traj.c. */
#ifdef QUBE_TRAJ_FILE
    if (qube_traj_open(QUBE_TRAJ_FILE, QUBE_TRAJ_COLUMN) != 0) {
        fprintf(stderr, "run_hardware: could not read the trajectory %s\n", QUBE_TRAJ_FILE);
        qube_log_close();
        qube_hw_close();
        return 1;
    }
    fprintf(stderr, "run_hardware: replaying %ld samples from %s\n",
            qube_traj_length(), QUBE_TRAJ_FILE);
#endif

    QUBE_MEM state;
    memset(&state, 0, sizeof(state));
    QUBE_RESET(&state);

    /* Timing mirrors the Julia loop: run the body, then sleep the remainder of Ts (relative
     * sleep, no absolute-schedule catch-up — so one slow step just stretches that period
     * instead of compressing the following ones). The dt/exec measured here are for the
     * summary line only; the program logs its own, from inside the tick. */
    const long N = (long)(QUBE_TF / QUBE_TS);
    struct timespec t0, start, done;
    clock_gettime(CLOCK_MONOTONIC, &t0);
    struct timespec prev = t0;
    double sum_dt = 0.0, max_dt = 0.0, max_exec = 0.0;
    long periods = 0;

    for (long i = 0; i < N && !stop_flag; ++i) {
        clock_gettime(CLOCK_MONOTONIC, &start);
        double dt = tsub(start, prev);    /* achieved period since previous step [s] */
        prev = start;

        /* One call: reads both encoders, computes, writes the motor voltage and appends a
         * row to the log. The returned output struct is deliberately unused. */
        QUBE_OUT out = QUBE_STEP(true, GAINS_PTR, AUTO_PTR, &state);
        (void)out;

        clock_gettime(CLOCK_MONOTONIC, &done);
        double exec = tsub(done, start);  /* body duration [s] */

        if (i > 0) { sum_dt += dt; if (dt > max_dt) max_dt = dt; periods++; }
        if (exec > max_exec) max_exec = exec;

        double remain = QUBE_TS - exec;
        if (remain > 0.0) {
            struct timespec ts;
            ts.tv_sec  = (time_t)remain;
            ts.tv_nsec = (long)((remain - (double)ts.tv_sec) * 1e9);
            clock_nanosleep(CLOCK_MONOTONIC, 0, &ts, NULL);   /* relative sleep */
        }
    }

    fprintf(stderr, "run_hardware: Ts=%.4f s | mean dt=%.4f s, max dt=%.4f s, "
                    "max exec=%.4f s over %ld periods | %ld rows in %s\n",
            QUBE_TS, periods > 0 ? sum_dt / (double)periods : 0.0, max_dt, max_exec,
            periods, qube_log_rows(), QUBE_LOG_FILE);
    if (qube_log_error()) fprintf(stderr, "run_hardware: the log was closed by a write error\n");

    /* Zeroes the motor and releases the board. */
    qube_hw_close();
    qube_log_close();
#ifdef QUBE_TRAJ_FILE
    if (qube_traj_error())
        fprintf(stderr, "run_hardware: the run outlived the trajectory (0 V was commanded)\n");
    qube_traj_close();
#endif
    return 0;
}

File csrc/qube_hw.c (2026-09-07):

/* See qube_hw.h. The HIL path here is the code that used to live in the
 * generated run_hardware.c control loop; moving it behind these four entry
 * points is what lets the controller do its own I/O on every target. */
#include "qube_hw.h"

#include <stddef.h>
#include <stdio.h>
#include <string.h>
#include <time.h>

#ifdef QUBE_HW_HAVE_HIL
#include "hil.h"
#include "quanser_messages.h"
#endif

#define QUBE_HW_COUNTS2RAD (2.0 * 3.14159265358979323846 / 2048.0)

static int    s_mode   = -1;    /* -1 = not open */
static double s_shoulder = 0.0;
static double s_elbow    = 0.0;
static double s_u        = 0.0;
static long   s_n_measure = 0;
static long   s_n_write   = 0;
static long   s_count_shoulder = 0;
static long   s_count_elbow    = 0;
/* Added to every shoulder reading: where the arm physically sat at `qube_hw_open`
 * (HIL mode only), so the arm need not be at its home position to calibrate. */
static double s_arm_offset = 0.0;

/* Loop diagnostics, latched inside the tick so the program can log them as ordinary
 * signals instead of the surrounding loop having to write a second file. `time` and `dt`
 * are latched by the encoder read, `exec` by the motor write, so a row assembled after the
 * write (which is what a data dependency on the applied voltage guarantees) carries this
 * tick's values. Wall clock rather than tick count on purpose: the point of these three is
 * to show where the loop failed to keep its period. */
static double s_t_first   = 0.0;   /* CLOCK_MONOTONIC at the first read after open */
static double s_t_measure = 0.0;   /* ... at this tick's read */
static double s_time      = 0.0;
static double s_dt        = 0.0;
static double s_exec      = 0.0;
static int    s_have_prev = 0;
static long   s_rt_n      = 0;     /* real-time pacing: calls so far ... */
static double s_rt_t0     = 0.0;   /* ... and CLOCK_MONOTONIC at the first of them */

static double qube_now(void) {
    struct timespec ts;
    clock_gettime(CLOCK_MONOTONIC, &ts);
    return (double)ts.tv_sec + (double)ts.tv_nsec * 1e-9;
}

static qube_hw_measure_fn s_cb_measure = NULL;
static qube_hw_write_fn   s_cb_write   = NULL;

/* Copied rather than aliased: callers (notably Julia) may pass a transient string. */
static char s_card_options[256] = QUBE_HW_DEFAULT_CARD_OPTIONS;

void qube_hw_set_card_options(const char *options) {
    if (options == NULL) { s_card_options[0] = '\0'; return; }
    size_t i = 0;
    while (options[i] != '\0' && i + 1 < sizeof(s_card_options)) {
        s_card_options[i] = options[i];
        i += 1;
    }
    s_card_options[i] = '\0';
}

const char *qube_hw_card_options(void) { return s_card_options; }

#ifdef QUBE_HW_HAVE_HIL
static const char board_type[]       = "qube_servo3_usb";
static const char board_identifier[] = "0";

static t_card   s_board;
static t_int32  s_counts0[2] = {0, 0};   /* homing offsets, subtracted from every read */
static const t_uint32 s_encoder_channels[2] = {0u, 1u};  /* 0 = shoulder, 1 = elbow */
static const t_uint32 s_analog_channel      = 0u;        /* motor voltage */
static const t_uint32 s_digital_channel     = 0u;        /* amplifier enable */

static int qube_hil_start(void) {
    t_double  voltage = 0.0;
    t_boolean enable  = 1;
    t_error   result  = hil_open(board_type, board_identifier, &s_board);
    if (result < 0) {
        char msg[512];
        msg_get_error_message(NULL, result, msg, sizeof(msg));
        fprintf(stderr, "qube_hw: hil_open failed (%d): %s\n", (int)result, msg);
        return -1;
    }
    /* Home in software: the encoder counters are left untouched
     * (hil_set_encoder_counts is deliberately NOT called -- zeroing the counters
     * has been observed to desync the driver's counter extension, producing
     * spurious 2^16-count jumps) and the initial counts become offsets. */
    /* Before touching the motor: pin the command-to-torque path (see qube_hw.h). */
    if (s_card_options[0] != '\0') {
        result = hil_set_card_specific_options(s_board, s_card_options,
                                               strlen(s_card_options));
        if (result < 0) {
            fprintf(stderr, "qube_hw: hil_set_card_specific_options(\"%s\") failed (%d)\n",
                    s_card_options, (int)result);
            hil_close(s_board);
            return -1;
        }
    }
    hil_write_analog(s_board, &s_analog_channel, 1, &voltage);
    hil_write_digital(s_board, &s_digital_channel, 1, &enable);
    hil_read_encoder(s_board, s_encoder_channels, 2, s_counts0);
    return 0;
}

static void qube_hil_stop(void) {
    t_double voltage = 0.0;
    hil_write_analog(s_board, &s_analog_channel, 1, &voltage);
    hil_close(s_board);
}

static void qube_hil_read(double *shoulder, double *elbow) {
    t_int32 counts[2] = {0, 0};
    hil_read_encoder(s_board, s_encoder_channels, 2, counts);
    s_count_shoulder = (long)counts[0];
    s_count_elbow    = (long)counts[1];
    *shoulder = (double)(counts[0] - s_counts0[0]) * QUBE_HW_COUNTS2RAD + s_arm_offset;
    *elbow    = (double)(counts[1] - s_counts0[1]) * QUBE_HW_COUNTS2RAD;
}

static void qube_hil_apply(double u) {
    t_double voltage = (t_double)u;
    hil_write_analog(s_board, &s_analog_channel, 1, &voltage);
}
#endif /* QUBE_HW_HAVE_HIL */

int qube_hw_have_hil(void) {
#ifdef QUBE_HW_HAVE_HIL
    return 1;
#else
    return 0;
#endif
}

int qube_hw_open(int mode, double arm_home_rad) {
    qube_hw_close();
    if (mode == QUBE_HW_MODE_HIL) {
#ifdef QUBE_HW_HAVE_HIL
        if (qube_hil_start() != 0) return -1;
#else
        fprintf(stderr, "qube_hw: built without HIL support "
                        "(compile with -DQUBE_HW_HAVE_HIL)\n");
        return -2;
#endif
    } else if (mode != QUBE_HW_MODE_CALLBACK) {
        fprintf(stderr, "qube_hw: unknown mode %d\n", mode);
        return -3;
    }
    s_mode = mode;
    /* Callback handlers return already-calibrated angles, so the offset is HIL-only. */
    s_arm_offset = (mode == QUBE_HW_MODE_HIL) ? arm_home_rad : 0.0;
    s_shoulder = 0.0;
    s_elbow = 0.0;
    s_u = 0.0;
    s_count_shoulder = 0;
    s_count_elbow = 0;
    qube_hw_reset_counters();
    return 0;
}

/* Zeroed here rather than in `qube_hw_open` so `time` starts at the first tick, not at the
 * board opening: opening homes the arm and can take a while, and a log whose first row is
 * at t = 0.4 s reads like a dropped start. */
void qube_hw_reset_timing(void) {
    s_have_prev = 0;
    s_time = 0.0;
    s_dt = 0.0;
    s_exec = 0.0;
    s_rt_n = 0;
    s_rt_t0 = 0.0;
}
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

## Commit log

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2026-07-20 Match QubePendulum to the QuanserInterface hardware model
    The Dyad QubePendulum was mirror-imaged relative to the QuanserInterface
    simulator (which is calibrated to the real QUBE-Servo hardware): the
    arm<->pendulum coupling sign was inverted, and the pendulum used a uniform-rod
    inertia instead of the hardware-matched value. This made the generated
    controller need per-plant sign flips to run on the QI simulator.
    Fixed in the dyad source (and regenerated):
    - QubePendulum: flip elbow_joint axis n = [1,0,0] -> [-1,0,0] (corrects the
    coupling sign; the arm already matched QI), and set the pendulum inertia
    Jp = 7*mp*Lp^2/12 to match QI's effective H22 (found by least-squares fit of
    the upri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
2026-07-20 Soften the LQR gains to reduce control chatter
    The previous LQR gains used R=10, giving an aggressive feedback
    (L = [-9.2, -94.1, -3.7, -11.4]) that amplifies sensor noise on hardware and
    causes shaky stabilization. Re-designed with a much softer control weighting
    (Q = diagm([1000,10,1,1]), R = 300 on the upright-linearized, discretized
    plant), giving L = [-1.72, -46.0, -1.06, -5.49] — 2-5x smaller across the board
    while keeping a solid closed-loop margin (spectral radius 0.985). Both the Dyad
    plant and the QuanserInterface simulator still swing up and stabilize.
    Note: the pendulum-angle gain (L2) cannot be lowered to the QuanserInterface
    reference (~24) on this model, because QubePendulu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
2026-07-21 Fix codegen for array-valued LQR gain L
    The switch to an array parameter `L` (instead of scalars L1..L4) broke the
    code generation two ways:
    - The dyad array literal used space-separated values, which the Dyad compiler
    parsed as subtraction, so the generated `L` default collapsed to a 1-element
    vector `[-30.257]` for a `[4]` parameter. Use comma separators (as elsewhere
    in the model) so it is the intended 4-vector.
    - src/codegen.jl still assumed scalar gains: `_make_runtime` referenced the
    removed `lqr.L1..L4`, and the parameter-value resolution called
    `Float64(...)` on every parameter, throwing on the array `L`. Read the array
    `lqr.L` directly and resolve array-valued parameter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
2026-07-21 Add homing + error-recovery state machine to the controller
    Implements the hardware control loop's structure in the synchronous program:
    - GoHome: homes the arm to 0 with a super-twisting sliding-mode controller on
    s = arm_velocity + 5*arm_angle (DiscreteComponents.SuperTwistingSMC, matching
    QuanserInterface.go_home), and reports `done` once the arm has stayed near home
    for `home_time`.
    - ErrorRecovery: overrides the runtime command with -0.5*arm_angle when the arm
    swings past ±110 deg (the out-of-bounds guard from the hardware loop).
    - RuntimeController: wraps Swingup with ErrorRecovery.
    - SwingupWithHoming: a two-state machine (top-level controller) that runs GoHome,
    switches t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
2026-07-21 Docstrings + icons for new controller components; GoHome reuses SuperTwistingSMC
    - Convert the block comments above ErrorRecovery, GoHome, RuntimeController and
    SwingupWithHoming into Dyad docstrings (rendered into the generated code).
    - Add icon metadata + assets/*.svg for the four new components.
    - Refactor GoHome to build its homing law from the shared
    DiscreteComponents.SuperTwistingSMC block (sliding surface formed by a Gain +
    Add, output saturated to ±th) instead of inlining the super-twisting equations.
    Verified: codegen still compiles SwingupWithHoming through stkcompile and the
    :julia/:c backends produce identical control signals.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
2026-07-21 Build controller logic from blocks + connections instead of equations
    Rework ErrorRecovery, GoHome and SwingupWithHoming so signal flow that was
    hidden inside ifelse/@clk equations is now explicit blocks and connections,
    making the GUI diagram informative:
    - ErrorRecovery: Abs -> GreaterThreshold -> Switch (was one ifelse).
    - GoHome: sliding surface via Gain+Add into SuperTwistingSMC, saturation via
    Limiter; home detection via Abs+LessThreshold+And; dwell counter via
    SampleTimeSource+Add+Switch+UnitDelay; done via GreaterEqualThreshold. Now a
    plain (unclocked) component whose clock is inferred from its discrete blocks.
    - SwingupWithHoming: the two-state machine is now a block network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
2026-07-21 Simplify hardware_swingup loop: state machine now lives in the controller
    The synchronous program (SwingupController) now performs homing, swing-up + LQR
    stabilization, error recovery and the out-of-bounds re-home state machine
    internally. Drop the hand-rolled equivalents from the hardware loop:
    - remove the pre-loop `u0 = 0.5*go_home(process)` bias,
    - remove the `if !(-deg2rad(110) <= y[1] <= deg2rad(110))` correction block and
    the `oob` counter,
    - remove the now-unused LQR gain `L` and scratch vectors.
    The loop now resets the controller (to start in the homing state) and each sample
    just measures -> `ctrl(y[1], y[2])` -> applies the voltage.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
2026-07-21 Fix compile_lustre sim path: drop array intermediate variable in LQRstabilizer
    `multibody(model, additional_passes=[SynchToolkit.compile_lustre])` errored with
    `KeyError: ...lqrstabilizer₊e(t) not found`: SynchToolkit's compile_lustre
    registers the declared array variable `e::Real[4]` as a generated var but never
    assigns it a clock, so the var_clocks lookup throws.
    Fold the error vector directly into the dot product instead of storing it in an
    intermediate array variable. `L` stays an array parameter and the control law is
    unchanged (uraw = dot(L, [0-θ, π-α, 0-θ̇, 0-α̇])).
    This is independent of the block-based refactor (reproduces at the previous
    commit); it was missed because th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
2026-07-22 Use `final` for parent->child parameter forwards
    Mark every place a parent parameter is forwarded to a sub-component parameter
    with `final`, so the parent parameter is the user-facing knob and the child is a
    hidden implementation detail (generated as a `bindings` entry rather than a
    symbolic default). Covers:
    - GoHome: smc.k/k2<-k/k2, lambda_gain.k<-lambda, limiter.y_max<-th,
    angle_ok/vel_ok/done_cmp thresholds.
    - ErrorRecovery: out_of_bounds.threshold<-arm_limit, recovery.k<-recovery_gain.
    - SwingupWithHoming: out_of_bounds.threshold<-arm_limit,
    increment.k<-oob_increment, fault.threshold<-oob_threshold.
    - EnergySwingup: limiter.y_max<-umax.
    - VelocityEstimator: exponentialfilter.a<-fi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
2026-07-23 Add FurutaExportC analysis: export swing-up controller as C
    A Dyad analysis (dyad/furuta_export_c.dyad + src/export_analysis.jl) that
    designs the LQR stabilizer gain from the penalty weights Q1/Q2 and exports the
    swing-up controller as standalone C into a user-specified output directory.
    Runnable from the Dyad Builder play button; results are reported as a table
    artifact listing the generated files and the exported step/reset symbol names.
    - src/codegen.jl: new design_lqr(; Ts, Q1, Q2) (linearize FurutaSwingup about
    upright, discretize, solve LQR), refactored out of test/runtests.jl so the
    analysis and the test share one implementation. build_discrete_controller
    gains optional L/umax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
2026-07-24 Add pendulum inertia identification example
    Estimate the QubePendulum inertias (Jr, Jp) from a recorded swing-up
    trajectory using an Unscented Kalman Filter prediction-error method from
    LowLevelParticleFilters (Gauss-Newton via LeastSquaresOptim). The script is
    structured around a single `tunable_syms` list so it can be extended to fit
    other parameters (br, bp, kt, Rm, ...) with no other changes.
    On swingup.csv the fit reduces prediction-error SSE ~26x (9.77 -> 0.37) and
    moves Jr 2.29e-4 -> 4.36e-5 (toward the QuanserInterface value 1.11e-5),
    confirming the nominal inertias are a poor fit. A final step redesigns the
    LQR gain from the identified parameters and prints it next to the baked-in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
2026-07-24 Use double-integrator covariance for pendulum identification R1
    The process noise models an unmodeled torque/acceleration disturbance on each
    joint. Passed through the double integrator (angle <- velocity <- acceleration),
    such a disturbance correlates a joint's angle and velocity noise -- they are not
    independent, so R1 must be block-structured rather than diagonal. Use
    double_integrator_covariance_smooth (continuous white noise, full rank,
    sample-time-invariant), which is the correct form since the noise is additive to
    the RK4 output rather than integrated through it. Each joint is now parameterized
    by a single physical intensity instead of two independently-settable noise levels.
    Co-Auth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
2026-07-27 Add discriminating input design for nominal vs identified parameters
    examples/input_design.jl designs a 60 s open-loop voltage trajectory that
    maximises the difference between the responses predicted by the `nominal` and
    `identified` parameter sets, so one hardware run can decide between them.
    Two stages: linearize both models about the hanging equilibrium and locate the
    band where |G_id - G_nom| peaks (the two sets predict pendulum resonances at
    ~1.3 and ~1.9 Hz), then optimise the amplitudes of a periodic 10 s multisine on
    that band against the nonlinear models. Feasibility is the binding constraint,
    not the voltage limit: the objective uses log1p(D) so a penalty on constraint
    excess reli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
2026-07-29 Externalize the hardware harness C into real source files
    `emit_hardware_harness` built `run_hardware.c` and the `Makefile` as interpolated
    Julia strings. That cost editor tooling on ~115 lines of C and invited escaping
    bugs: two crept into a single `fprintf` recently -- a `\"` that reached the C
    unescaped, and a `\n` that became a literal newline inside a string literal.
    Neither is expressible once the C is a file.
    The Makefile needed nothing from Julia at all -- every `$(...)` in it was an
    escaped *make* variable, and it detects the SDK layout itself -- so it is now
    `csrc/Makefile`, copied verbatim like `qube_hw.c` already was. That also retires
    the `\t` escaping, which is load-bearing in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
    [run_hardware.c]
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2026-07-30 fix kst live plotting
    [run_hardware.c]
2026-07-30 Log the run from inside the program, and bind umax at the root
    Three changes to the models, all so that a program carries everything about a run
    that is not timing.
    `HardwareDiagnostics` exposes what a control loop can only measure about itself:
    elapsed time, the achieved period, the read-to-write duration and the raw encoder
    counts. They are latched in csrc/qube_hw.c -- `time`/`dt` by the encoder read,
    `exec` by the motor write -- and read back through registered operators, so they
    are available on every target the program compiles for, exactly like the device I/O
    itself. `exec` measures read to write, which is everything the node does bar the
    logging call, so it runs slightly short of the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
    [qube_hw.c]
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2026-07-30 Test the consolidated layer, and drive the rig through it
    New coverage for what is new: the swing-up run log written from inside the program
    (including the assertion that pins the diagnostics' scheduling -- a nonzero `exec` in
    the *first* row is only possible if the reads happen after the motor write),
    `run_program!` against a simulated axis with the program's own logged period agreeing
    with what the loop measured, the friction experiment exported to C and built, the
    per-target log-path rules, and the shared analysis base including the cases that must
    fail loudly (parameters that identify no analysis, or more than one).
    The `partial` guard now covers all three bases. `QubeHardwareRunBase` i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
2026-07-31 Start the live plot on this run's log, not the last one's
    The viewer was launched while the previous run's log was still in place, and the run
    then truncated that file and refilled it underneath. kst binds to what it read
    first and never shows the new content -- while continuing to *read* the file the
    whole time, which is why read activity looked healthy and the window stayed on the
    old run. A frozen plot of a run that really happened, which is the worst kind.
    Measured rather than reasoned about, after two wrong theories (the file being empty
    at launch, and kst refusing to re-read a shrinking file) were eliminated by probing
    `/proc/PID/io`: read volume proves polling, not refreshing. Screen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
2026-07-31 Take deploy_host at face value
    Setting `deploy_host` on the friction analysis did nothing: `run_on_target` only looked
    at it inside the `export_c` branch, so with `export_c` left false the host was ignored
    and the program ran in this process, against whatever card the workstation has. On a
    workstation with the QUBE attached to the Pi that is `hil_open` failing with -108 while
    the named host sits there with the device on it.
    A non-empty `deploy_host` now implies exporting C, because it cannot mean anything else:
    an in-process run happens in the Julia process, so it cannot happen on another machine,
    and C sources are the only thing there is to send. The decision is extracted into
    `run_target`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
2026-07-31 Stop the friction analysis pinning deadband compensation off
    The reset two commits ago removed this from the analysis' `extends` line and verified
    it gone, but the file was rewritten from a stale editor buffer before the commit, so
    `9fee767` went in with the source still pinning `deadband_compensation=0.0` while the
    generated spec it committed said `""`. Source and generated disagreed, and the
    analysis would have run the sweep with compensation off -- the configuration measured
    as worse (0.59 V of command and 1.9 deg of hold error, against 0.1 V and 0.2 deg).
    Verified after the compile this time rather than before it, which is what let the
    inconsistency through.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
2026-07-31 Collect identification data with a Dyad program, not QuanserInterface
    test/hardware_discrimination.jl drove the QUBE through QuanserInterface, which the test
    environment no longer has, so the script was dead. The experiment is now a model and an
    analysis like the other two, and the driver script is twenty lines that call it.
    `TrajectorySource` is the mirror image of `DataLogger`: one designed sample per tick, read
    from *inside* the program through csrc/qube_traj.c, so the replay is the program's own
    doing on the Julia backend, the in-process C backend and exported C alike rather than
    something a surrounding loop feeds it. The file name travels the same way the log's does --
    a structural par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
    [run_hardware.c]
2026-09-05 Try the ACADOSMPC AD Jacobian backend: an MPC swing-up controller
    Add FurutaMPC, the swing-up controller with the LQR stabilizer replaced by an
    MPCComponents.ACADOSMPC whose prediction model is the multibody QubePendulum
    itself, compiled with multibody() and differentiated numerically with the new
    jacobian_backend = ForwardDiff option (the compiled multibody model references
    cached linear solves that the symbolic backend cannot reconstruct). The MPC
    bounds the motor voltage and the arm angle (the end stops) and uses the LQR
    cost-to-go about upright as terminal cost; the energy swing-up and NearTop
    switch are the existing components. FurutaMPCHardware is the hardware program
    (in-program I/O a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
2026-09-05 MPC only: the ACADOSMPC swings up and balances, Ts = 10 ms, Np = 60
    Drop the energy swing-up, the NearTop switch and ErrorRecovery from FurutaMPC:
    one nonlinear MPC does both jobs, with the upright reference, the LQR cost-to-go
    about upright as terminal weight, the voltage and arm constraints as before, SQP
    (30 iterations) with a shifted warm start over a 0.6 s horizon. The shoulder/elbow
    programs keep the same interface; the runtime-settable parameter is now
    command_umax, a clamp before the amplifier for a first run at reduced voltage,
    and the log loses the MPC-active column. EnergySwingup is back to main's version.
    Pushed before any closed-loop verification, at the user's request; the wei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
2026-09-05 Pin the whole MPC dependency stack in the package's sources
    Registry SynchToolkit 0.5.0 cannot compile a program with array clocked
    variables (the MPC's outputs) and fails in stkcompile with
    `KeyError: key (control_system₊mpc₊u(t))[1] not found`; the branch MPCComponents
    pins (mpccomponents/compat-synchjulia-0.6, JuliaComputing/SynchToolkit.jl#185)
    can. Only MPCComponents was pinned here, so an environment built from this
    project resolved SynchToolkit from the registry. Pin SynchToolkit, SynchJulia,
    SynchCompiler, DiscreteComponents, LinearMPC and the acados JLLs in Project.toml
    and test/Project.toml, make generate_mpc_controller refuse a SynchToolkit without
    the fix with a message that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
2026-09-06 Real-time pacing for the simulated hardware model, the MPC debug GUI, more finals
    HardwareDiagnostics gains `realtime`: with it the component waits, after the
    motor write, until the wall clock reaches the next tick (hw_realtime_wait, a
    ccall into csrc/qube_hw.c like the other diagnostics; the anchor is reset with
    the timing) and reports the overrun in `late`. That lets FurutaMPCHardware be
    run against the device as a *simulation* -- an ODE solver stepping the clocked
    partition -- which is how the MPC's predicted trajectories and residuals end up
    in a solution object for MPCComponents.mpc_gui. run_mpc_hardware_model does
    that run (output_trajectories and realtime on, a zero-voltage warm-up so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
    [qube_hw.c]
2026-09-06 MPC swing-up: a tuning that swings up and balances in simulation within 1.3 ms a tick
    Found by simulating the compiled program against the multibody model with
    encoder quantization and the discrete velocity estimators, and by tracing the
    failing solves. What had to change:
    - Weights. The swing-up and the balancing want different weightings, and the
    balancing has to be design_lqr's (Q1 = diag(1000, 10, 1, 1), Q2 = 100), so
    the stage cost is blended between that and a swing-up set (diag(10, 300, 1, 1),
    Q2 = 10) by the distance from upright (SwingupBlend -> ACADOSMPC.blend_weights);
    the terminal weight is that LQR design's cost-to-go, explicit (Qf from
    furuta_mpc_terminal_weight) so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
2026-09-06 MPC swing-up: LQR weights with a soft terminal set instead of blended weights
    The weight blending is gone; the stage cost is design_lqr's throughout and the
    terminal cost its LQR cost-to-go about upright. The swing-up comes from a soft
    terminal set: the pendulum angle at the end of the horizon is constrained to
    within 0.6 rad of upright (terminal_constrained, terminal_constraints_soft,
    slack weight 1e3). The pendulum angle is wrapped to [0, 2π) again, which the
    fixed terminal set needs; the 2π jump at the bottom costs a failed solve that
    reset_on_failure recovers. Velocity bounds, filter constant 0.8, 10 V, HPIPM
    condensed to 5 stages, Levenberg-Marquardt 1 stay. NearestUpright, SwingupBle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
2026-09-07 test harness: declare LinearAlgebra and Printf, bind QuanserComponents
    Four pre-existing breakages that stopped the suite from loading at all, kept
    apart from the review that found them so they can be dropped or redone
    independently.
    `test/Project.toml` did not declare `LinearAlgebra` or `Printf`, both of which
    the tests use, so loading failed with `ArgumentError: Package LinearAlgebra not
    found in current path`. `runtests.jl` bound only the `QC` alias while reaching
    for `QuanserComponents.` directly in about a hundred places, and the `QC = QC`
    at the top of the "shared analysis base" testset made `QC` a local variable
    there, so it threw before the first `@test`.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
2026-09-07 Review: the MPC prediction model as a Dyad component, and less repetition
    The review asked for two things: fewer Julia functions called from Dyad, since
    one hides the model it builds from the diagram; and less code saying the same
    thing twice.
    `FurutaPredictionModel` (dyad/furuta_mpc.dyad) is the first. The MPC's
    prediction model used to be assembled in `furuta_mpc_dynamics` out of a
    `World`, a `QubePendulum` and a hand-written `pendulum_energy_ratio` equation
    restating `mp`, `l` and `Jp` from the parameter set. It is a Dyad component
    now -- that plant plus the one signal the swing-up term weights -- reading the
    parameters off `qube` so the energy cannot drift from the plant it predicts,
    an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
2026-09-07 Check in the designed identification input, one column of it
    `input_design.csv` is the sequence `FurutaIdentification` replays and the fixture
    four testsets need, and it was gitignored -- so a fresh checkout errored in
    those four until someone ran the half-hour input design in
    examples/input_design.jl. Checking it in as written was unappealing at 232 kB of
    text, so this drops the two thirds of it that carry no information.
    The `time` column went first. It held `(k-1) * Ts` and nothing else -- verified
    against all 12000 rows, zero mismatches -- while the trajectory is indexed by
    tick and the sample time is the model's `Ts`, so the column could only restate
    what the replay already knows. `u`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
    [input_design.csv]
2026-09-07 Reach the MPC's solver settings, and record what they are worth
    MPCComponents' sparse AD Jacobian backends (JuliaComputing/MPCComponents.jl#19) looked
    like they might cut the Furuta MPC's solve time. They do not, and neither does the rest
    of that pull request; measuring it turned up two things worth fixing here and one worth
    writing down.
    `qp_cond_N` was unreachable. It is a structural parameter of `FurutaMPC`, and Dyad's
    `__`-path overrides collect their values into a `Dict{String, SymbolicT}`, so
    `control_system__qp_cond_N = 5` arrived at `build_acados_mpc` as a symbolic and was
    rejected with `expected Integer`. `FurutaMPCHardware` now forwards it as a real keyword,
    the way it already for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
2026-09-07 A multirate MPC: 1 kHz state estimation, 125 Hz control
    FurutaMPCMultirate is FurutaMPC split across two clocks -- the encoders read
    and the state estimated at Ts_fast, the MPC solved at Ts -- with
    FurutaMPCMultirateSwingup and FurutaMPCMultirateHardware as the simulated and
    hardware loops. All three are new; nothing existing changes behaviour.
    The extra rate is not the point on its own. VelocityEstimator is a backward
    difference through an exponential filter, a constant-velocity estimator, and a
    swinging pendulum's velocity is never locally constant, so its estimate
    carries an acceleration-induced bias that no bandwidth choice removes.
    Sampling the same estimator faster is close to worthle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
2026-09-07 Tests for the multirate MPC
    Two testsets in mpc_tests.jl. The program one checks the mechanics of a
    two-clock node: the divisors, that the driver ticks the fast clock, that 17
    ticks give 17 encoder reads and 3 motor writes, that the MPC fires on ticks 1,
    9 and 17 with its outputs `nothing` in between, that `reset!` puts the tick
    phase back, and that a non-integer or unity rate ratio and a C export are all
    refused. The model one checks that the two partitions really are separate --
    sample counts and tick spacings taken from each variable's own timebase, not
    from `sol.t` -- that the motor voltage changes only on the MPC's clock, and
    that the pendulum still swings up and stays within 0.1 rad of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
